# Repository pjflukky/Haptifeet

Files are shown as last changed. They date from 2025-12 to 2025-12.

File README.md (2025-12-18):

# HaptiFeet

A hands-free navigational aid for the visually impaired that uses haptic feedback to convey spatial awareness.

## Overview

HaptiFeet is a wearable assistive device designed to help visually impaired individuals navigate their environment through haptic feedback. The system uses LiDAR sensing to detect nearby objects and provides intuitive vibration patterns through eight independently controlled haptic modules positioned around the user's waist.

**Team:** Isak Keyes, Ben Wolf, Pakorn Jantacumma, Wei Chen Zhang  
**Course:** UW Madison ECE453 FA25

## Features

- **360° Spatial Awareness**: LiDAR sensor provides 0.72° resolution with up to 500 samples per rotation
- **Hands-Free Operation**: Worn around the waist, leaving hands free for other tasks
- **8 Haptic Zones**: Individual vibration motors cover a 120° forward field of view in 15° sectors
- **Distance Mapping**: Vibration intensity increases as objects get closer
- **Adjustable Sensitivity**: Potentiometer allows users to scale overall haptic intensity
- **Persistent Calibration**: EEPROM stores haptic calibration data across power cycles
- **Rechargeable**: Built-in battery management with USB-C charging

## Hardware Architecture

### Core Components

- **Microcontroller**: PSoC6 (CY8CPROTO-063-BLE)
- **Distance Sensor**: LiDAR with UART communication, 10Hz scanning frequency
- **Haptic Actuators**: 8x Eccentric Rotating Mass (ERM) motors
- **Haptic Drivers**: DRV2605 I²C-controlled haptic driver chips with auto-calibration
- **Memory**: EEPROM for storing calibration presets
- **Power Management**: 
  - MP2637GR-Z battery charging IC
  - TLV62569DBVR boost converter (3.6V → 5.0V)
  - TPS62569DBVR buck converter (5.0V → 3.3V)
  - Automatic switching between USB and battery power
  - Simultaneous charging and operation support

### Power System Features

- Rechargeable lithium-ion batteries
- USB-C charging port
- Boost converter for battery voltage regulation
- Buck converter for logic voltage supply
- Current and voltage limiting for safe operation
- Over-temperature, reverse voltage, and short circuit protection
- Visual LED indicators for power status (5V and 3.3V)

### PCB Design

- **Main Board**: 100mm × 35mm custom PCB
- **Haptic Modules**: 8 individual 35mm × 35mm boards
- Bidirectional analog multiplexers for individual haptic addressing
- Clock gating on I²C lines to enable same-address communication
- Shunt resistor-based ID assignment for each haptic module

## Software Architecture

### Module Structure

```
task_core.c          # Main control loop and state management
├── task_lidar.c     # LiDAR data acquisition and parsing
├── task_poten.c     # Potentiometer reading for sensitivity adjustment
├── task_haptics.c   # Haptic motor control and intensity mapping
└── task_eeprom.c    # Calibration data persistence
```

### Control Flow

1. **Initialization**
   - Read EEPROM for saved haptic calibration presets
   - If presets found → Load and apply to haptic drivers
   - If no presets → Run calibration routine and save to EEPROM

2. **Main Loop**
   - Read LiDAR sensor data (360° scan at 10Hz)
   - Read potentiometer for global intensity scaling
   - Process LiDAR data into 8 sectors (15° each, covering 120° FOV)
   - Calculate vibration intensity for each sector based on minimum distance
   - Update haptic motors via I²C communication

### LiDAR Processing

- Continuous rotation scanning at 10Hz
- Data collected via UART communication
- 120° field of view segmented into 8 sectors
- Distance measurements mapped to haptic intensity
- Frame validation and error checking

## Enclosure Design

- 3D-printed custom housing
- Ergonomic waist-mounted design
- Integrated mounting for:
  - LiDAR sensor (forward-facing)
  - Main PCB
  - Battery pack
  - Power switch
  - USB-C charging port
  - Potentiometer knob
  - Status LEDs

## Building the Project

### Hardware Requirements

- PSoC6 development kit (CY8CPROTO-063-BLE)
- LiDAR sensor module
- 8x ERM haptic actuators
- 8x DRV2605 haptic driver boards
- Custom PCB (files in `/hardware/pcb/`)
- Power management components
- 3D-printed enclosure (files in `/hardware/enclosure/`)

### Software Requirements

- PSoC Creator IDE
- Cypress PSoC Programmer

### Building Firmware

1. Open the project in PSoC Creator
2. Build the project (Build → Build HaptiFeet)
3. Program the PSoC6 device

## Usage

1. **Power On**: Flip the power switch
2. **Wait for Initialization**: Green LED indicates system ready
3. **Adjust Sensitivity**: Turn potentiometer to set comfortable vibration level
4. **Navigate**: Wear device around waist with sensor facing forward
   - Stronger vibrations = closer objects
   - Vibration location corresponds to object direction

## Challenges Overcome

- **Enclosure Alignment**: Adjusted case holes through careful modification
- **Power Supply**: Buck converter current limitations resolved with supplementary module
- **Battery Fit**: Modified battery holder to accommodate larger cells
- **PCB Fixes**: Hand-soldered missing connections and resistor adjustments
- **PSoC Power**: Switched to 5V supply via KitProg for reliability

## Future Improvements

- [ ] Integrate PSoC directly into main PCB
- [ ] Reduce PCB footprint and eliminate unused space
- [ ] Switch to lithium polymer batteries for slimmer profile
- [ ] Separate LiDAR housing for better weight distribution
- [ ] Embed cable connectors into housing for cleaner design
- [ ] Integrate haptic modules directly into wearable strap

## Project Structure

```
HaptiFeet/
├── firmware/
│   ├── task_core.c
│   ├── task_lidar.c
│   ├── task_haptics.c
│   ├── task_eeprom.c
│   └── task_poten.c
├── hardware/
│   ├── pcb/
│   │   ├── main_board/
│   │   ├── haptic_modules/
│   │   └── schematics/
│   └── enclosure/
│       └── 3d_models/
├── docs/
│   └── presentation.pdf
└── README.md
```

## Schematics

### Main Board Connections
- MCU module with EEPROM, LiDAR, and haptic headers
- Power management (boost, buck, charging IC)
- USB interface
- Potentiometer input

### Haptic Modules
- DRV2605 driver with ERM actuator
- Analog multiplexer for I²C addressing
- ID resistor configuration

See `/hardware/pcb/schematics/` for complete circuit diagrams.

## License

This project was developed as part of ECE453 at UW Madison.

## Acknowledgments

- UW Madison ECE Department
- ECE453 Course Staff
- Team members: Isak Keyes, Ben Wolf, Wei Chen Zhang

## Contact

For questions or collaboration opportunities, please reach out through the GitHub repository.

---

**Note**: This project was completed in Fall 2025 as a senior design project for ECE453 at the University of Wisconsin-Madison.

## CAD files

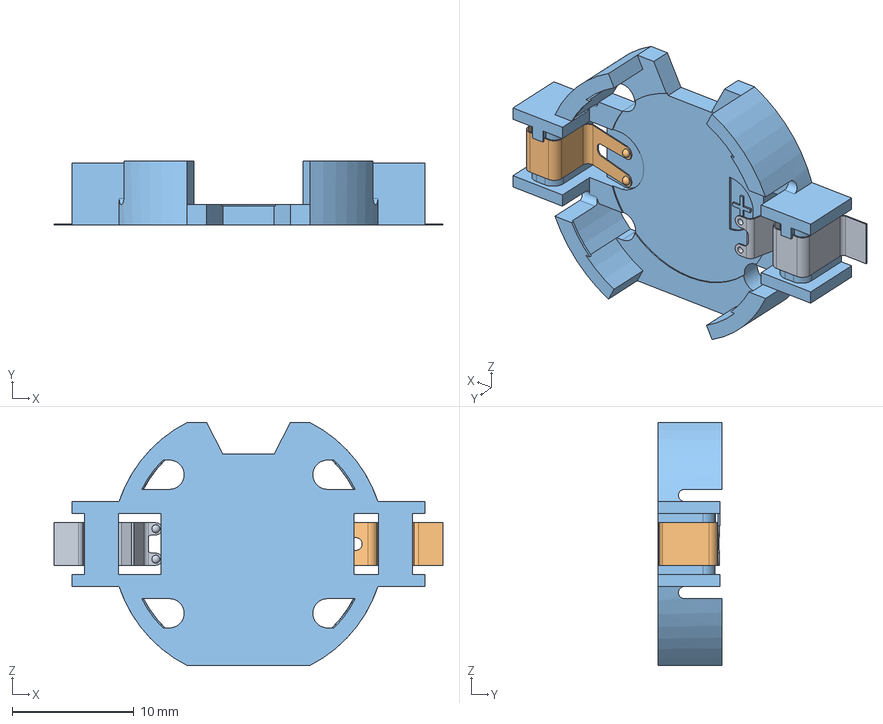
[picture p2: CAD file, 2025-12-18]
ece453-team03-mcu-carrier-main/3D/BU2032SM-HD-GCR2032 Battery Holder.stp
32.0 x 5.30 x 20.0 mm

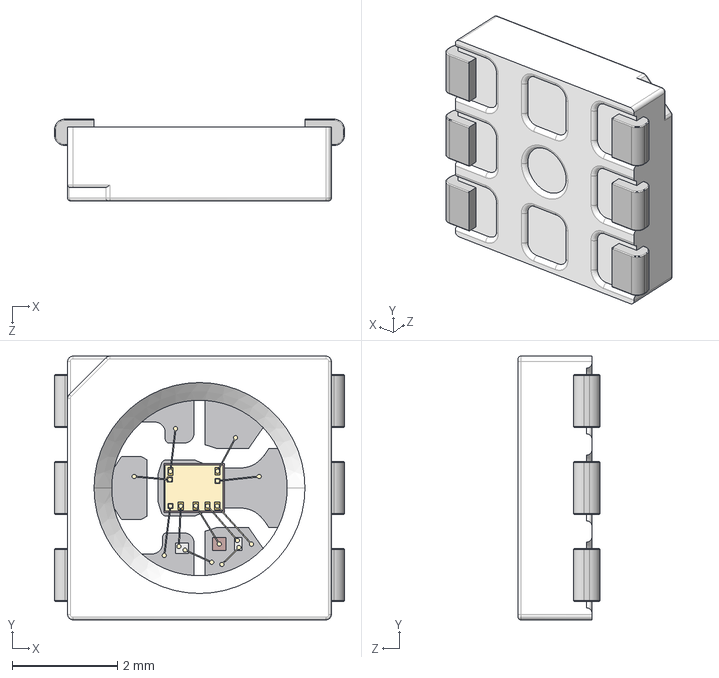
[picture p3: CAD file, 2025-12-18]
ece453-team03-mcu-carrier-main/3D/APA102C.STEP
5.50 x 5.00 x 1.55 mm

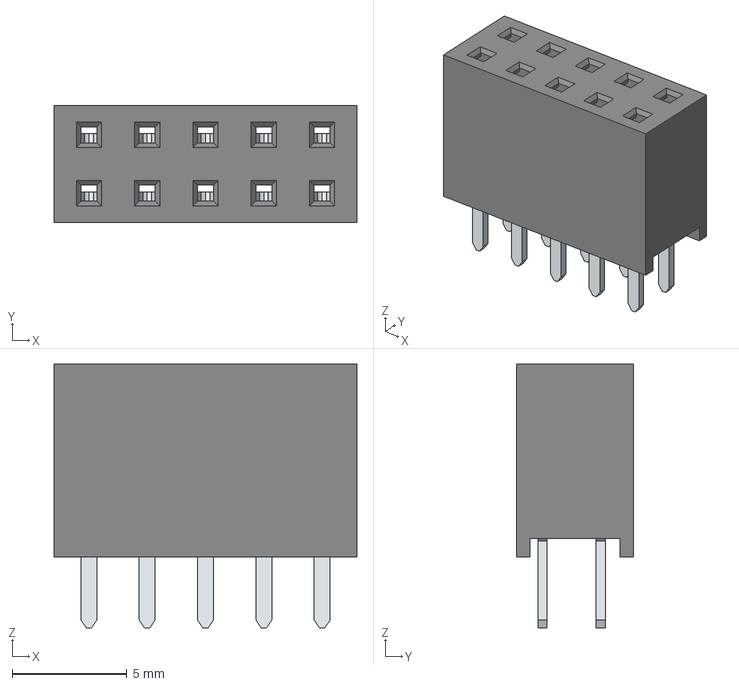
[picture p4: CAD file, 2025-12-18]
ece453-team03-mcu-carrier-main/3D/STEP-61301021821-rev1.stp
13.2 x 5.08 x 11.5 mm
6130xx21821_PIN x 10

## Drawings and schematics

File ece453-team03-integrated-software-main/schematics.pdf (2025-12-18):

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
# Revision & History

Title:

Size: | Sheet:
A of
Project | Rev:
1 4

## College of Engineering 1415 Engineering Drive Madison, WI 53706

ECE453 F24 Staff Dev Board | A
Date: | Revision: | Comments:
| | Initial Revision

## Revision History:

## Additional Notes:

# Revision History and Table of Contents

## Important Notes about this Schematic:

LAYOUT NOTE:
Layout notes in red text boxes give infomation regarding layout requirements.

DESIGN NOTE:
Design notes in gray text boxes give infomation about design
requirements and descisions.

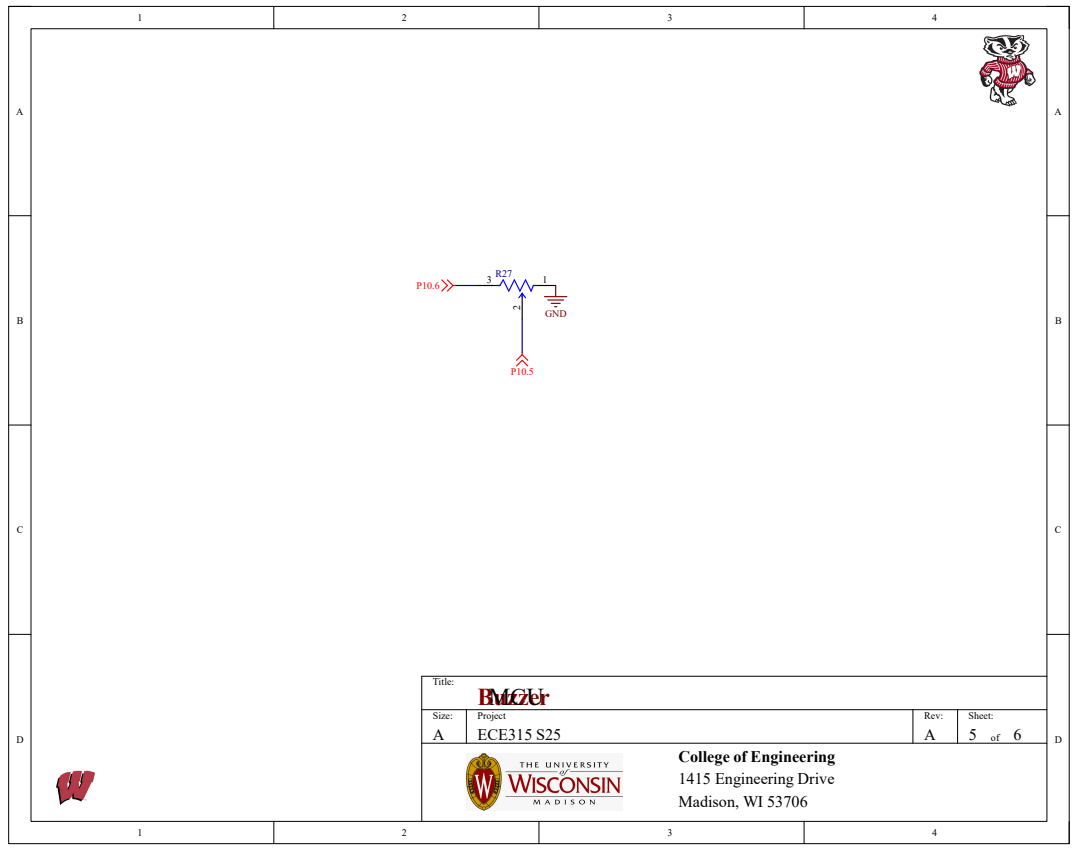
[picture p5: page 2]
Buzzer; Title:; Size:; Sheet:; Project; Rev:; ECE315 S25; GND; MCU

College of Engineering
1415 Engineering Drive
Madison, WI 53706

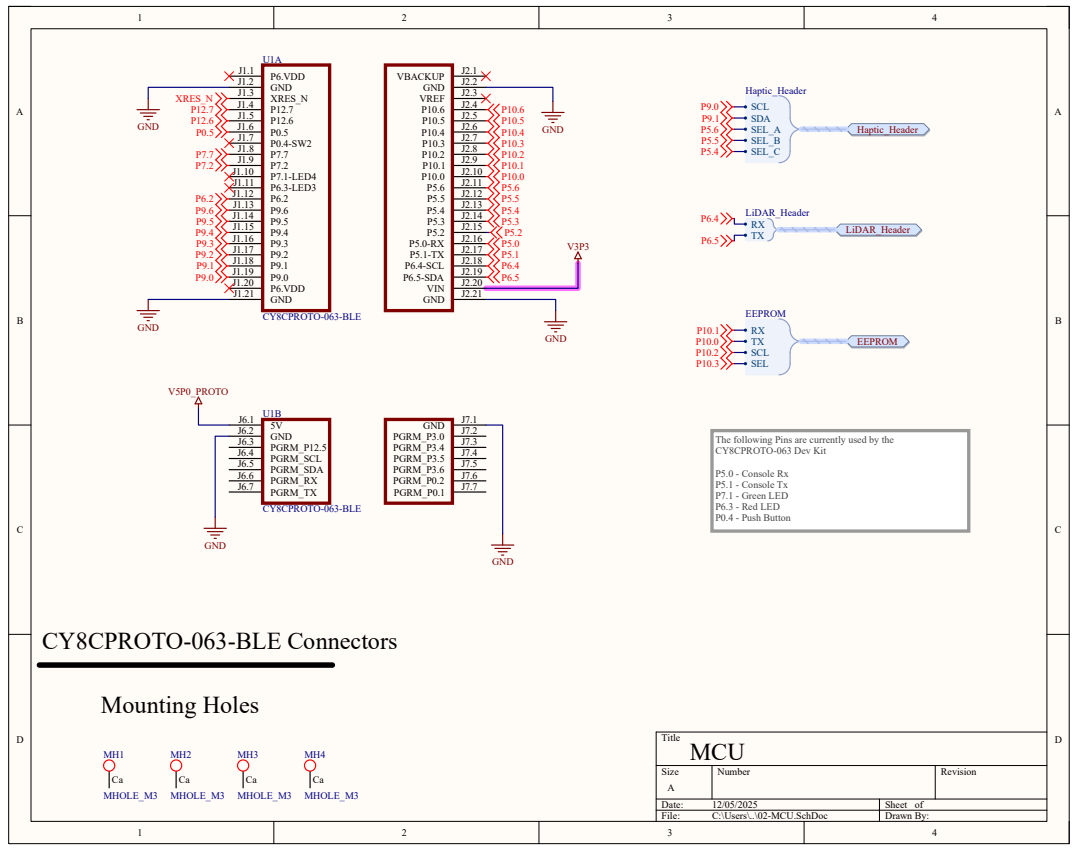
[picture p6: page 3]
Title; Size; Number; Revision; Date:; Sheet of; File:; C:\Users\..\02-MCU.SchDoc; Drawn By:; GND; Mounting Holes; CY8CPROTO-063-BLE Connectors; P6.VDD J1.1 GND J1.2 XRES_N J1.3 P12.7 J1.4 P12.6 J1.5 P0.5 J1.6 P0.4-SW2 J1.7 P7.7 J1.8 P7.2 J1.9 P7.1-LED4 J1.10 P6.3-LED3 J1.11 P6.2 J1.12 P9.6 J1.13 P9.5 J1.14 P9.4 J1.15 P9.3 J1.16 P9.2 J1.17 P9.1 J1.18 P9.0 J1.19 P6.VDD J1.20 GND J1.21; VBACKUP; VREF; P6.4-SCL; P6.5-SDA; VIN; CY8CPROTO-063-BLE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

The following Pins are currently used by the
CY8CPROTO-063 Dev Kit

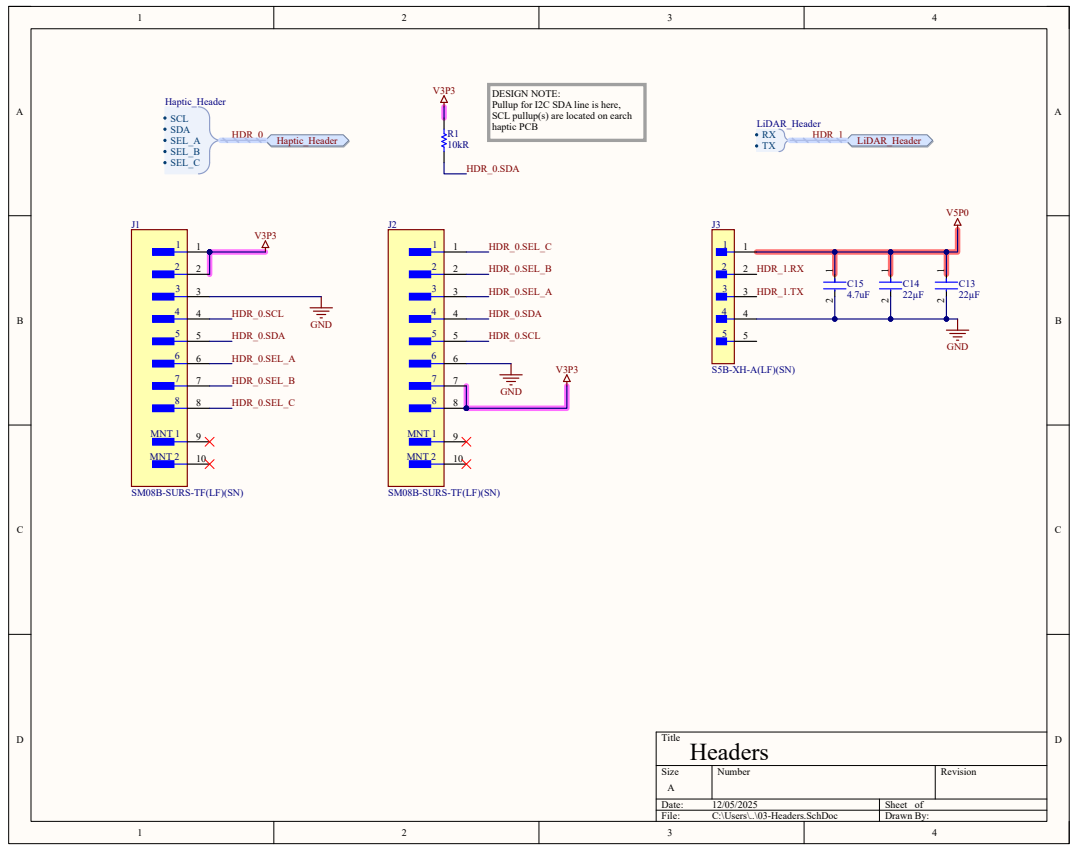
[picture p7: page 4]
Title; Size; Number; Revision; File:; C:\Users\..\03-Headers.SchDoc; Drawn By:; MNT 1; MNT 2; HDR_0.SCL; HDR_0.SDA; HDR_0.SEL_A; HDR_0.SEL_B; HDR_0.SEL_C; GND; SCL SDA SEL_A SEL_B SEL_C; Haptic_Header; Haptic_Header HDR_0; LiDAR_Header; HDR_1; HDR_1.TX; HDR_1.RX; Headers

DESIGN NOTE:
Pullup for I2C SDA line is here,
SCL pullup(s) are located on earch
haptic PCB

SM08B-SURS-TF(LF)(SN)

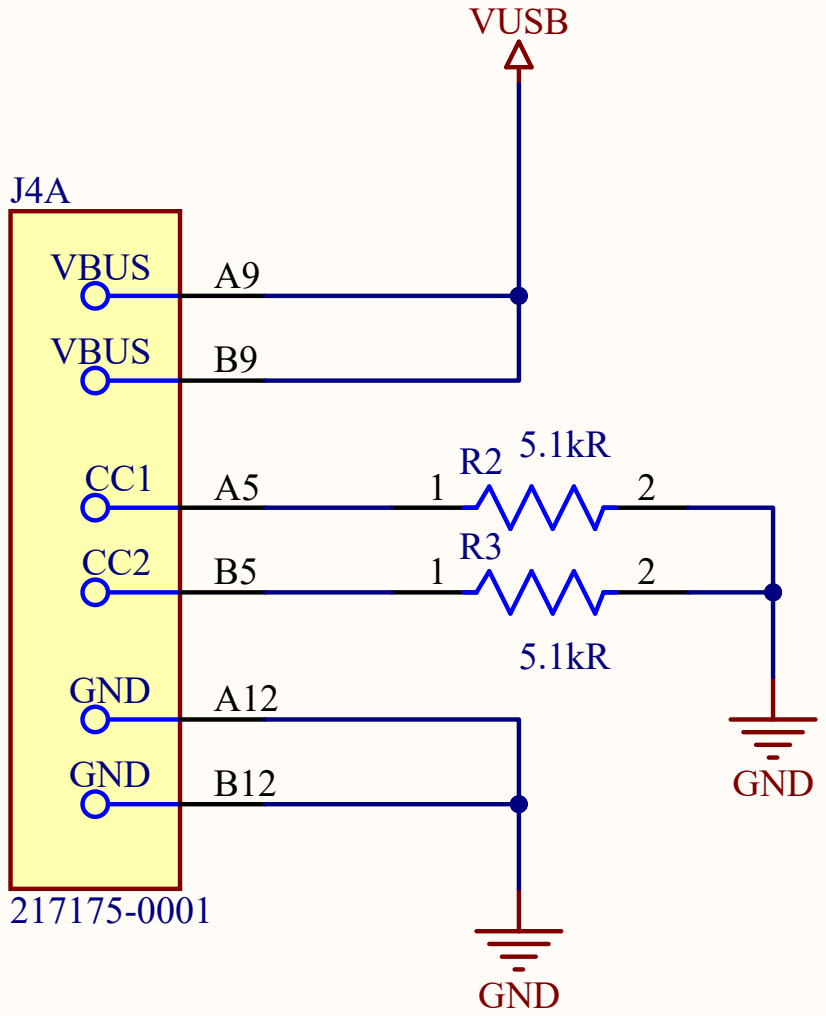
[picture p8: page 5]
Title; Size; Number; Revision; File:; C:\Users\..\04-USB.SchDoc; Drawn By:; VBUS; GND; VUSB; USB

# VUSB 1 2

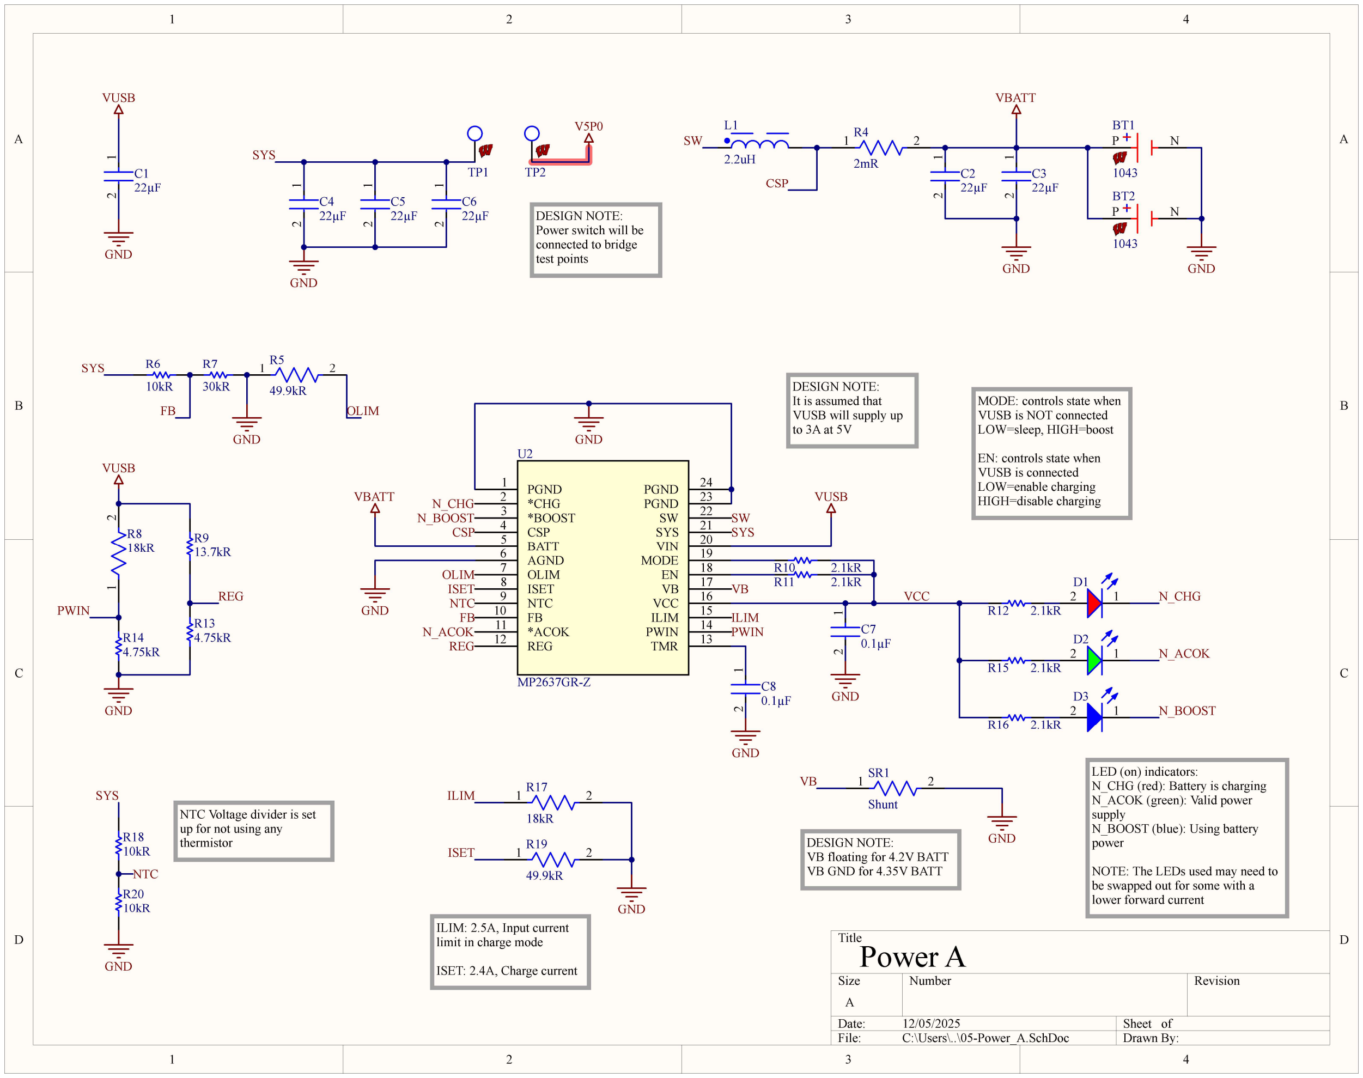
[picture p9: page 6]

D D

C C

B B

A A

Title

Size | Number | Revision
File: | C:\Users\..\05-Power_A.SchDoc | Drawn By:

PGND 1
*CHG 2
*BOOST 3
CSP 4
BATT 5
AGND 6
OLIM 7
ISET 8
NTC 9
FB 10
*ACOK 11
REG 12 | TMR | 13 PWIN | 14 ILIM | 15 VCC | 16 VB | 17 EN | 18 MODE | 19 VIN | 20 SYS | 21 SW | 22 PGND | 23 PGND | 24

U2

MP2637GR-Z

DESIGN NOTE:
It is assumed that
VUSB will supply up
to 3A at 5V
GND

VB

LED (on) indicators:
N_CHG (red): Battery is charging N_ACOK (green): Valid power supply
N_BOOST (blue): Using battery power

NOTE: The LEDs used may need to be swapped out for some with a lower forward current

MODE: controls state when
VUSB is NOT connected
LOW=sleep, HIGH=boost

EN: controls state when
VUSB is connected
LOW=enable charging
HIGH=disable charging

NTC

R18
10kR

R20
10kR

NTC

N_CHG
N_BOOST

N_ACOK

P N

BT1

1043

P N

BT2

1043

SW

VUSB

R10 | 2.1kR
R11 | 2.1kR

CSP

VBATT

1 2 R4

2mR

L1

2.2uH
CSP

SW

VBATT

REG | 1 2

C8
0.1µF

1 2
C4

22µF 1 2
C5

22µF 1 2
C6
22µF | 1 2
C2

22µF 1 2
C3
22µF

1 2 R17

18kR

PWIN

ILIM | 1 2
C7
0.1µF

ILIM

N_CHG

N_ACOK

N_BOOST

R12 | 2.1kR
R15 | 2.1kR
R16 | 2.1kR

VCC

DESIGN NOTE:
VB floating for 4.2V BATT
VB GND for 4.35V BATT
VB | 1 | 2 SR1

Shunt

2 1

D1

2 1

D2

2 1

D3

OLIM

R6
10kR

FB

FB

R7
30kR

C1
22µF

OLIM

ISET

ISET

# VUSB 1 2 R8

18kR

R9
13.7kR

R13
4.75kR

GND

GND

GND | GND

R14
4.75kR

PWIN

REG

1 2 R19

49.9kR

ILIM: 2.5A, Input current
limit in charge mode

ISET: 2.4A, Charge current

NTC Voltage divider is set up for not using any
thermistor

SYS

SYS
TP1 TP2

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
V5P0

DESIGN NOTE:
Power switch will be
connected to bridge
test points

1 2 R5

49.9kR

SYS

SYS

# Power A

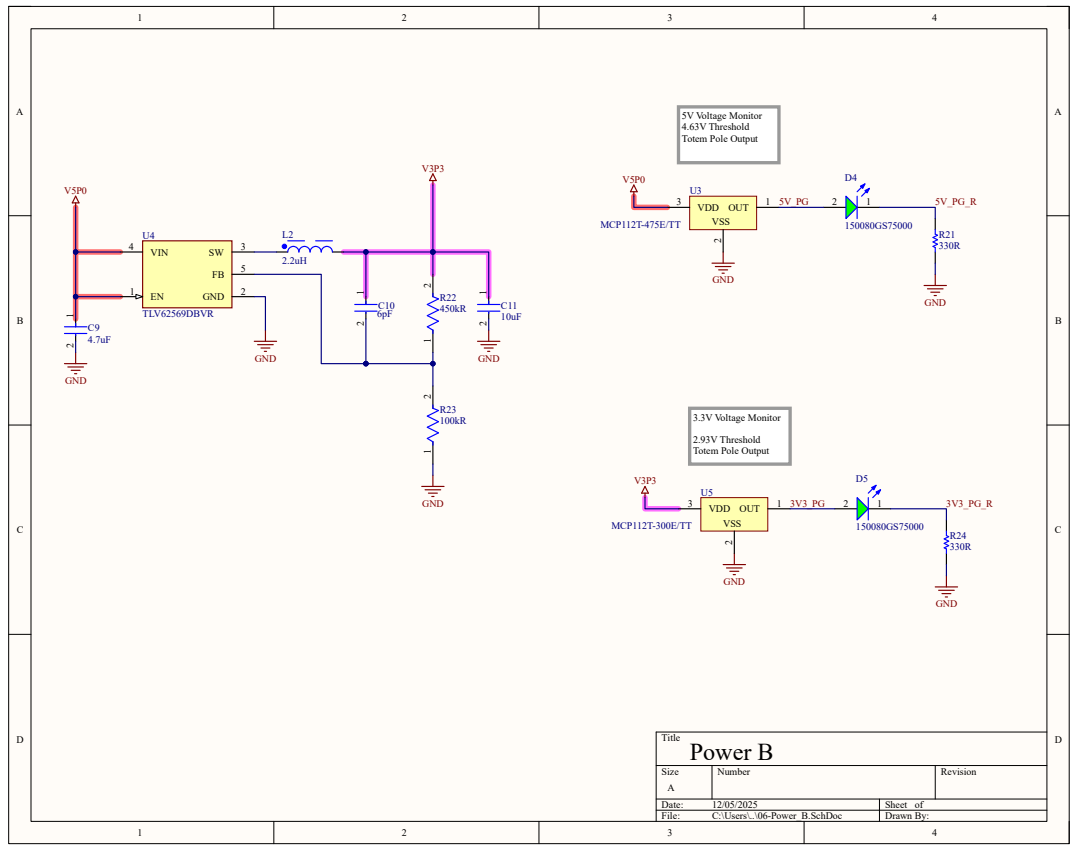
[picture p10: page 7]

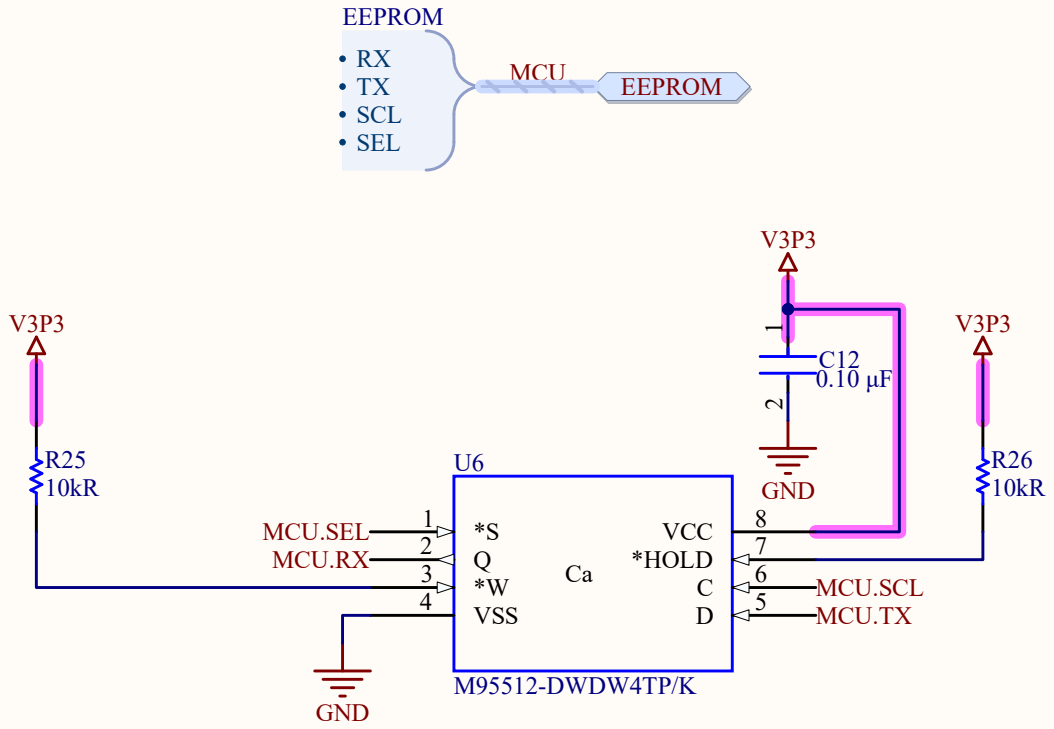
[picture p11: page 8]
Title; Size; Number; Revision; File:; C:\Users\..\07-EEPROM.SchDoc; Drawn By:; VSS 4; *HOLD; VCC; M95512-DWDW4TP/K; GND; RX TX SCL SEL; EEPROM; EEPROM MCU; MCU.RX; MCU.SEL; MCU.TX; MCU.SCL

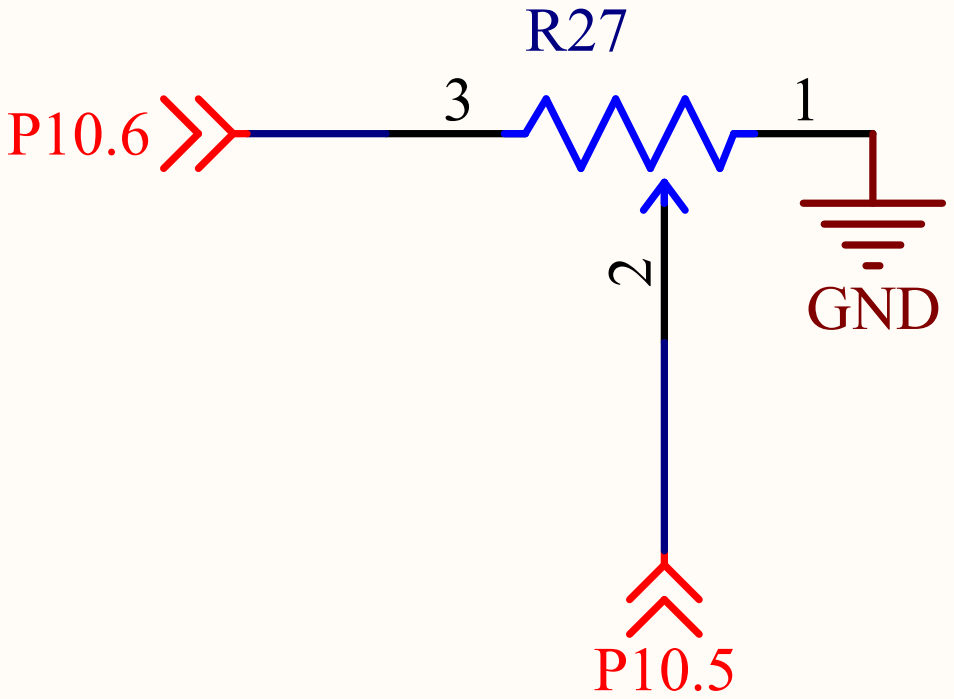
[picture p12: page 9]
Title; Size; Number; Revision; File:; C:\Users\..\08-Potentiometer.SchDoc; Drawn By:; Potentiometer; GND

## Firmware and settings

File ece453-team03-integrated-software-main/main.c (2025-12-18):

/**
 * @file main.c
 * @author Joe Krachey (jkrachey@wisc.edu)
 * @brief
 * @version 0.1
 * @date 2024-05-14
 *
 * @copyright Copyright (c) 2024
 *
 */
#include "main.h"
#include "source/app_hw/i2c.h"
#include "source/app_hw/spi.h"
#include "source/app_hw/task_console.h"
#include "source/app_hw/task_eeprom.h"
#include "source/app_hw/task_haptics.h"
#include "source/app_hw/task_poten.h"
#include "source/app_hw/task_lidar.h"
#include "source/app_hw/task_core.h"

int main(void)
{
    cy_rslt_t rslt;

    __enable_irq();

    /* Initialize the device and board peripherals */
    rslt = cybsp_init();
    CY_ASSERT(rslt == CY_RSLT_SUCCESS);

    rslt = i2c_init();
    // output error msg if initialization fails
    if (rslt != CY_RSLT_SUCCESS)
    {
        debug_printf("I2C Initialization Failed!\n");
    }
    CY_ASSERT(rslt == CY_RSLT_SUCCESS);
    
    rslt = spi_init();
    if (rslt != CY_RSLT_SUCCESS)
    {
        debug_printf("SPI Initialization Failed!\n");
    }
    CY_ASSERT(rslt == CY_RSLT_SUCCESS);

    task_haptics_init();
    task_eeprom_resources_init(&Semaphore_SPI, &mSPI, EEPROM_CS_N);

    task_console_init();

    task_core_init();

    task_poten_init();

    task_lidar_init();

    /* Start the FreeRTOS scheduler */
    vTaskStartScheduler();

    // Unreachable
    for (;;)
    {
    }
}

/* [] END OF FILE */

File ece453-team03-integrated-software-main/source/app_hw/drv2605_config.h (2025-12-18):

/**
 * @file drv2605_config.h
 * @author Isak Keyes
 * @brief Configuration header for the DRV2605 haptic driver
 * 
 * This file contains the actuator-specific configuration parameters
 * for the DRV2605 haptic driver.
 * 
 * @date 2025-11-05
 */
#ifndef __DRV2605_CONFIG_H__
#define __DRV2605_CONFIG_H__

/**
 * ============[ Background Information]============
 * 
 * Actuator Types:
 * - Linear Resonant Actuator (LRA): Vibration is produced by applying AC signal to
 *      a voice coil which moves a spring-mounted mass.
 *    > Adjustable amplitude, essentially fixed frequency (freq. can technically be controlled
 *      but deviating from resonant frequency greatly reduces performance and efficiency)
 * - Eccentric Rotating Mass (ERM): Vibration is produced by spinning an off-center mass
 *      using a DC motor.
 *    > Frequency and amplitude are coupled
 *    > slower response time due to motor inertia
 * 
 * Other Actuator Types (not being used here):
 * - Linear Magnetic Ram (LMR): A wideband voice coil actuator similar to LRA but
 *      without a spring-mounted mass. This is a newer technology and although very promising,
 *      it is currently prohibitively expensive. (See Titan Haptics "TacHammer" line)
 * - Piezoelectric Actuator: Uses piezoelectric materials to create vibration by mechanical
 *      deformation. These are best for short pulses, and have relatively low displacement.
 * 
 * ============[ Actuator Parameter Information]===========
 * Note: The information below only pertains to closed-loop operation of LRA and ERM actuators.
 * 
 * Actuator Configuration Parameters:
 * - N_ERM_LRA: Selects between ERM (0) and LRA (1) operation
 * - Rated Voltage: Maximum steady-state voltage for the actuator
 * - Overdrive Clamp Voltage: Maximum voltage applied during acceleration/deceleration
 * - Drive Time (LRA Mode): Duration of 1/2 period at the resonant frequency
 * - Drive Time (ERM Mode): Sample rate of back-EMF detection
 * TODO: FB_BRAKE_FACTOR, LOOP_GAIN, etc.?
 * 
 * LRA Parameter Calculations:
 * - Rated Voltage = (255/5.3)(V_rms*sqrt(1-lra_resonant_frequency*(4*t_s + 300e-6)))
 *    > V_rms: maximum steady-state rms voltage specified by manufacturer
 *    > lra_resonant_frequency: Resonant frequency of the LRA in Hz
 *    > t_s: Sample time in seconds (default is 300us)
 * - Overdrive Clamp Voltage = V_peak * (255/5.6)
 *    > V_peak: Maximum voltage applied during acceleration/deceleration, if max voltage
 *              is specified in rms use V_peak=V_rms*sqrt(2)
 * - Drive Time = 5000/lra_resonant_frequency - 5
 *    > lra_resonant_frequency: Resonant frequency of the LRA in Hz
 * 
 * ERM Parameter Calculations:
 * - Rated Voltage = V_dc * (255/5.6)
 *    > V_dc: Maximum steady-state DC voltage specified by manufacturer
 * - Overdrive Clamp Voltage
 *   = V_od * ((DriveTime+IDissTime+BlankingTime)/(DriveTime - 300e-6)) * (255/5.44)
 *    > V_od: Maximum voltage applied during acceleration/deceleration
 *    > IDissTime: = 75e-6 s (default)
 *    > BlankingTime: = 75e-6 s (default)
 *    > DriveTime: = 0x13 = 19 (default)
 */

// Values used to select from predefined actuator configurations
#define CONFIG_VG0832013D 0 // 235Hz 1G LRA: VG0832013D
#define CONFIG_VL91022_160_320H 1 // 160/320Hz 3G LRA: VL91022-160-320H (bidirectional)
#define CONFIG_VLV281813_65H 2 // 65Hz 4.8G LRA: VLV281813-65H
#define CONFIG_VLV101040A 3 // 170Hz 2.75G LRA: VLV101040A (small square)
#define CONFIG_VG2080001_175H 4 // 175Hz 3.2G LRA: VG2080001-175H (large coin)
#define CONFIG_VG2230001H 5 // 70Hz 3.5G LRA: VG2230001H (eq. to PS5 controller haptic)
#define CONFIG_VZ7AL2B1692082 6 // 12kRPM 5.1G ERM: VZ7AL2B1692082

// Select the desired configuration here
#define CONFIG CONFIG_VZ7AL2B1692082
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
